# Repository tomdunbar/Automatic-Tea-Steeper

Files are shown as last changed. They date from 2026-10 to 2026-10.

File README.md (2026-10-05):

# Automatic Tea Steeper

A gravity-powered, electronics-free mechanical contraption that automatically steeps a tea bag for approximately five minutes, rings a bell once when steeping is complete, and lifts the tea bag out of the water.

The mechanism is essentially a clock built around a **flying pendulum escapement**, but without gears. The goal is functional mechanical art: a device that would look at home in a **Victorian inventor's parlor**.

> [!IMPORTANT]
> **Prototype / pre-fabrication design**
>
> The design has not yet been fabricated and validated as a complete assembly.
>
> The Bill of Materials (BOM) contains an **Updates** column documenting design changes made after the current CAD models and fabrication drawings were produced. Where an update is explicitly listed in the BOM, it represents the newer design intent. The CAD, STEP files, DWG files, and PDF drawings are being revised part-by-part to incorporate those changes.
>
> **Do not assume the current CAD and PDF drawings are fully synchronized with the BOM.**

## Overview

The device is powered by gravity. A suspended weight descends and pulls a string that drives both the main vertical shaft and the wheel/drum assembly.

A flying pendulum escapement slows the descent of the weight. A tea bag is attached to a peg on the wheel so that the wheel's rotation repeatedly raises and lowers the tea bag in a mug.

At the end of the steeping cycle:

1. The descending weight begins to load a small platform.
2. The platform causes the ball track to pivot.
3. A ball bearing or marble rolls down the track and strikes a bell once.
4. Rotation of the ball track also raises a bent lifting rod, which lifts the tea bag out of the mug.

The target steeping time is approximately **5 minutes**.

## Design Goals

- Fully mechanical operation — no electronics.
- Gravity-powered operation.
- Approximately five-minute steeping cycle.
- Repeated raising and lowering of the tea bag during steeping.
- Single audible bell strike when steeping is complete.
- Automatic removal of the tea bag from the water at the end of the cycle.
- Visually attractive brass / bronze / stainless-steel construction.
- An aesthetic inspired by Victorian scientific instruments and small model engines.
- A design that can be fabricated by a conventional machine shop using a mill and lathe, with CNC used where helpful.

## Main Mechanism

The main weight pulls a string as it descends. The string is wrapped around the main vertical shaft and around a drum on the horizontal wheel shaft.

As the string pays out:

- the main vertical shaft rotates;
- the wheel and drum rotate;
- the flying pendulum escapement controls the rate of rotation; and
- the tea bag moves up and down in the mug.

The flying pendulum uses offset upper and lower static arms. A small angular offset between the arms helps the pendulum string disengage cleanly and engage the upper arm first as it travels around the mechanism.

## Resetting the Device

To reset the steeper:

1. Place the flying pendulum bob onto the wire hook on the pendulum arm.
2. Turn the crank to rewind the drive string and raise the main weight.
3. Loop the pendulum bob over the upper static-arm support to prevent the mechanism from running.
4. Attach the tea-bag string to the peg on the wheel.
5. Position the mug.
6. Release the pendulum bob to start the steeping cycle.

## Steeping-Complete Mechanism

The notification mechanism is intended to strike a bell **one time** after approximately five minutes.

As the main weight reaches the bottom of its travel, it applies a small force to a platform. This pivots the ball track and releases a ball bearing or marble. The ball rolls down the track, strikes the bell, and is caught in a separate shallow dish.

A bent rod attached to the rear of the ball track acts as the **tea-bag lifter**. When the track pivots, the rod rotates upward and lifts the tea bag out of the mug.

## Major Subassemblies

- Main pillar and support
- Upper static arms
- Lower static arms
- Rotating / flying-pendulum assembly
- Wheel and drum
- Steeping-complete notification mechanism
- Tea-bag lifter
- Wooden base

## Design Parameters

Current design targets include:

| Parameter | Design goal / current value |
|---|---:|
| Steeping time | ~5 minutes |
| Main-weight travel | ~300 mm |
| Main shaft speed | >= 9 seconds/revolution |
| Main rotating rod diameter | 3 mm |

The steeping time is expected to depend on several variables, particularly the flying-pendulum string length. Other influences include pendulum mass, main-weight mass, static-arm spacing and angular offset, friction, and the amount of drive string released per revolution.

## Repository Status and Source Hierarchy

This repository is currently being organized and the design files are being reconciled.

| Source | Current role |
|---|---|
| **BOM — Updates column** | Latest design intent for the specific changes listed there |
| Native CAD / editable CAD | Intended to become the primary geometry source as parts are revised |
| STEP files | Neutral 3D exchange files; some currently predate BOM updates |
| DWG / fabrication drawing source | Drawing source; some currently predate BOM updates |
| PDF fabrication drawings | Published/printable drawing output; some currently predate BOM updates |
| Design Overview | Explanatory documentation; not a fabrication-control document |

The goal is for every fabrication part to have a synchronized set of:

1. editable/native CAD;
2. STEP export;
3. fabrication drawing source; and
4. PDF fabrication drawing.

## Planned Repository Organization

```text
Automatic-Tea-Steeper/
├── README.md
├── LICENSE
├── CHANGELOG.md
├── BOM/
│   └── BoM.xlsx
├── CAD/
│   ├── source/          # Editable/native CAD going forward
│   └── STEP/            # Neutral 3D exports
├── Drawings/
│   ├── source/          # Editable drawing files
│   └── PDF/             # Fabrication PDFs
├── Docs/
│   ├── Automatic_Tea_Steeper_Design_Overview.pptx
│   └── images/
└── Archive/
    └── original-cad-package/
```

The exact folder structure may evolve while the original CAD package is being reconciled.

## Design History / Roadmap

- [x] Concept and hand sketches
- [x] Initial CAD model and fabrication drawing package
- [x] Bill of Materials
- [x] Initial public GitHub repository
- [ ] Reconcile BOM design updates with CAD
- [ ] Establish editable native CAD source for revised parts
- [ ] Regenerate synchronized STEP files and fabrication PDFs
- [ ] Complete DFM / drawing review with machinist
- [ ] Fabricate first-round parts
- [ ] Test assembly and mechanism
- [ ] Revise design based on test results
- [ ] Fabricate second-round parts
- [ ] Complete and document final assembly

## Inspiration and References

The design was inspired in part by:

- **Chronova Engineering — bimetallic tea-monitoring mechanism**  
  https://www.youtube.com/watch?v=oJzy1vk2zyc

- **Kontax Stirling engines** — particularly the visible mechanical construction and brass/aluminum model-engine aesthetic  
  https://stirlingengine.co.uk/

- **Flying pendulum escapements**  
  Introduction: https://www.youtube.com/watch?v=z8V6RMJbHJc  
  Reference drawings: https://www.woodenclocks.co.uk/clock-17/

These references are provided for context and inspiration; third-party images, videos, trademarks, and designs remain the property of their respective owners.

## License

The original hardware design files in this repository are intended to be released under the **CERN Open Hardware Licence Version 2 – Permissive (CERN-OHL-P-2.0)**.

Commercial use is expressly welcome. You are free to build, modify, manufacture, and sell products based on this design, subject to the attribution and notice requirements of CERN-OHL-P-2.0.

See [`LICENSE`](LICENSE) for the complete license terms.

Third-party reference images, linked videos, trademarks, and other externally sourced material are **not** relicensed under the project license unless explicitly stated.

## Contributing

Fabrication, machining, DFM, CAD, and mechanism feedback is welcome. Issues and pull requests are especially useful for:

- identifying ambiguous or missing dimensions;
- improving machinability;
- correcting drawing/CAD inconsistencies;
- documenting fits and tolerances;
- reporting build results; and
- proposing improvements based on physical testing.

## Credits

Original mechanical concept and design: **Tom Dunbar**

Initial CAD and drawing package was produced from the original concept and hand drawings with outside CAD assistance.

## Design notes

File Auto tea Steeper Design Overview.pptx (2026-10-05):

## Automatic Tea Steeper Contraption Design Overview

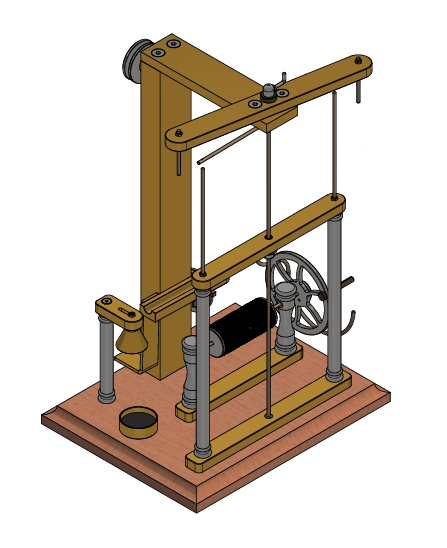
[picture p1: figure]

Design by Tom Dunbar

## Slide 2

This is a design for an automatic tea steeping contraption that is gravity powered and steeps a tea bag for approximately 5 minutes. After the steeping is complete, a bell is rung one time and the tea bag is lifted from the water. The contraption is based around a flying pendulum escapement so it contains no gears, despite it essentially being a clock.
The contraption was inspired by this delightfully over-engineered tea temperature monitoring mechanism: https://www.youtube.com/watch?v=oJzy1vk2zyc&list=PLxYRkul9JZoOfj6--7C8BmSLWSMhE7KK8&index=25&pp=gAQBiAQB
From this video, I liked the notification mechanism so much, I incorporated it into my design. I also like the aesthetic and functionality of the Kontax Stirling engine (https://stirlingengine.co.uk/products/KS90R-Ross-yoke-Aluminium-Stirling-Engine-p593670073), so I used some parts of it in the design. The goal is to create something that would look at home in a Victorian inventor’s parlor. As such, I did not want to use any electronics and wanted to use a ‘natural’ energy source e.g. gravity or the heat from the hot water.

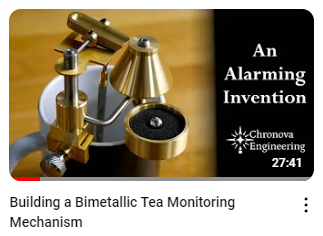
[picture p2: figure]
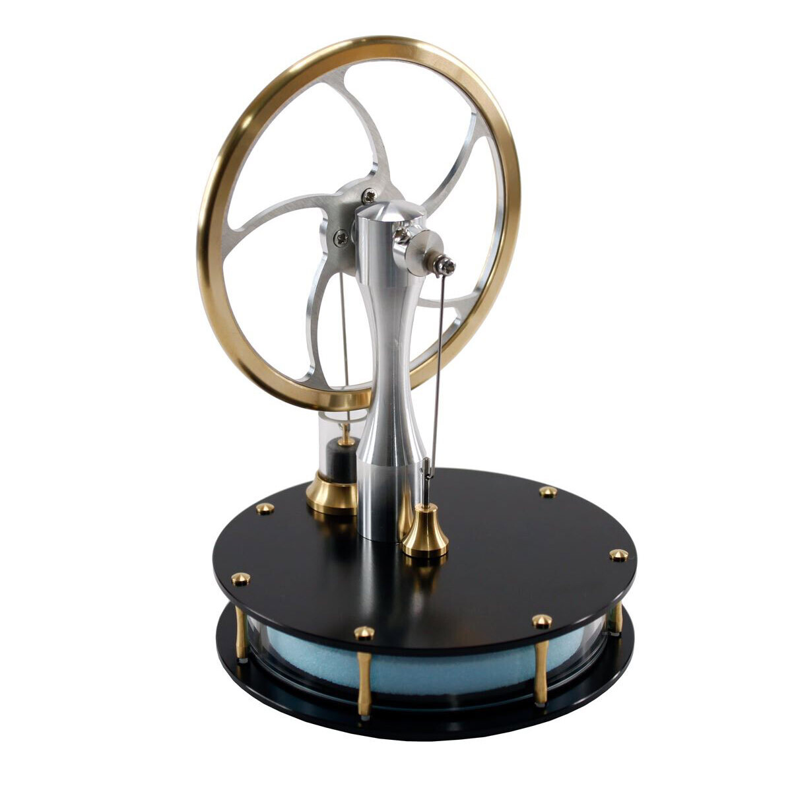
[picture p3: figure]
KS90 Aluminium Stirling Engine

## Main Mechanism Overview

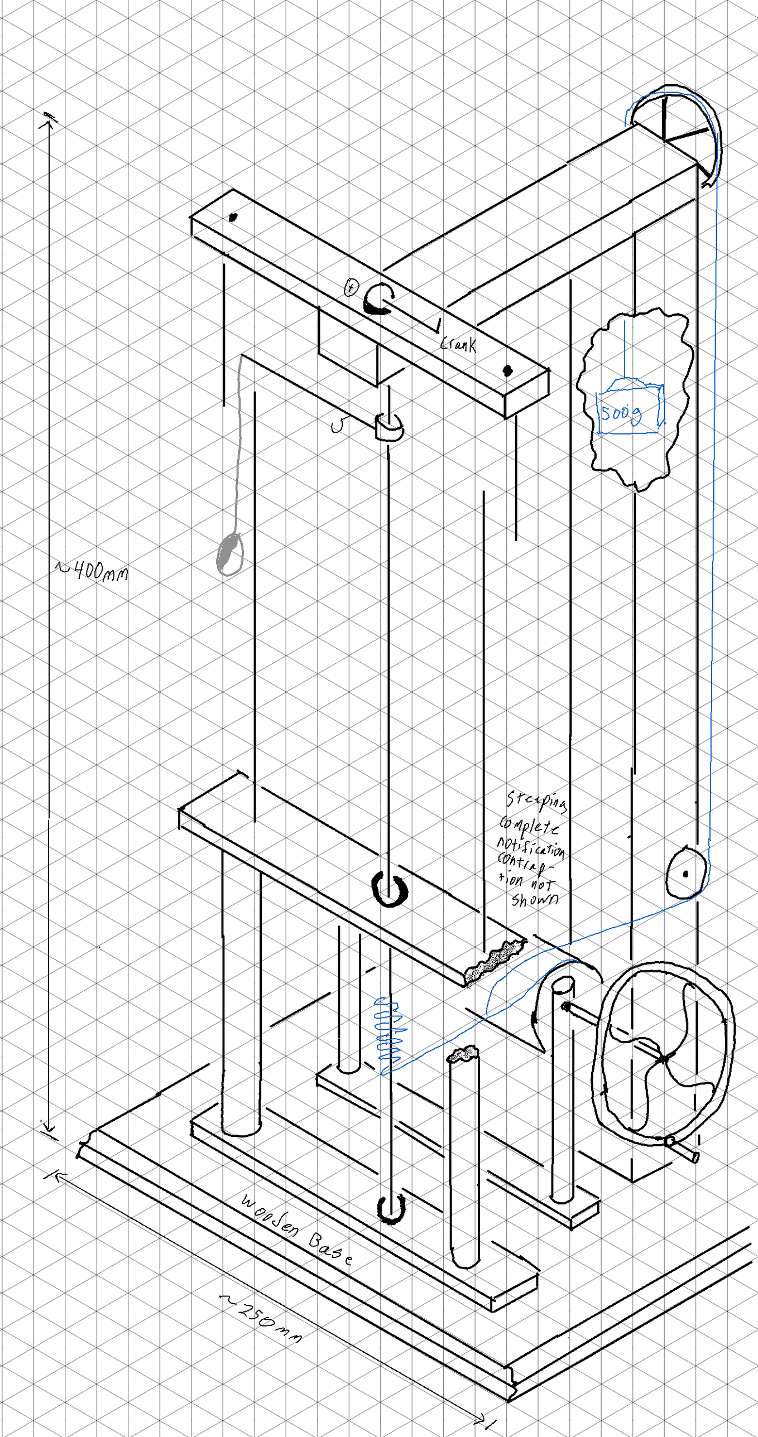
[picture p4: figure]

The mechanism works by gravity pulling the weight down, pulling on the string (blue).
The string is wrapped around a main vertical shaft and a drum. The drum is on a horizontal shaft with a wheel. As the string is played out, it causes the main vertical shaft to rotate as well as the drum/wheel to rotate.
The main shaft has a flying pendulum escapement to slow the weight’s decent.
A tea bag’s string is attached to a peg on the wheel and a mug of hot water is positioned below the wheel. As the wheel rotates, it slowly steeps the tea bag up and down.
As discussed later, after 5 minutes there is a steeping complete notification that rings a bell one time to alert the tea drinker that the tea is ready, similar to the notification in the inspiration video. The mechanism also lifts the tea bag out of the water.

## Flying Pendulum Escapement

- The link below is a good introduction to a flying pendulum and discusses some of the critical dimensions:
- https://www.youtube.com/watch?v=z8V6RMJbHJc
- The link below provides some good technical drawings of the escapement and some of the dimensions are visible in the PDF that you can view online. I used some of these dimensions when designing the device.
- https://www.woodenclocks.co.uk/clock-17/
- The following video is a bit long, but provided the original a-ha moment for how to actually accomplish the auto-steeping mechanism. The main mechanism is essentially a re-arrangement of his contraption:
- https://www.youtube.com/watch?v=uuelh5Yt9-Q

## Sub Assembles

- Main pillar and Support
- Upper static arms
- Lower static arms
- Rotating assembly
- Wheel & Drum
- Steeping complete notification contraption
- Wooden Base

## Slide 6

A slight offset (~10 degrees) between the upper and lower arms allows the string the disengage cleanly and helps it engage on the upper arm first when it swings around.
In this view, the pendulum is rotating counter-clockwise.

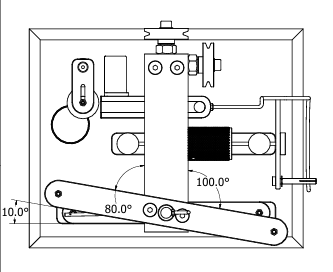
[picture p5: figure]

## Resetting the device

To reset the device, the flying pendulum bob is placed onto the wire hook that is on the pendulum arm. This allows the user to spin the crank without the pendulum bob wrapping around the static arms. This will wind up the string and prepare the weight for its next decent.
The pendulum bob is then looped over the upper static arm support beam to prevent the pendulum arm from moving (as seen in this video: https://www.youtube.com/watch?v=z8V6RMJbHJc)
When the pendulum is prevented from moving, the user can attach a tea bag’s string to the peg on the wheel and prepare a mug of hot water.
Un-looping the pendulum bob and letting go is all that is needed to start the main mechanism.

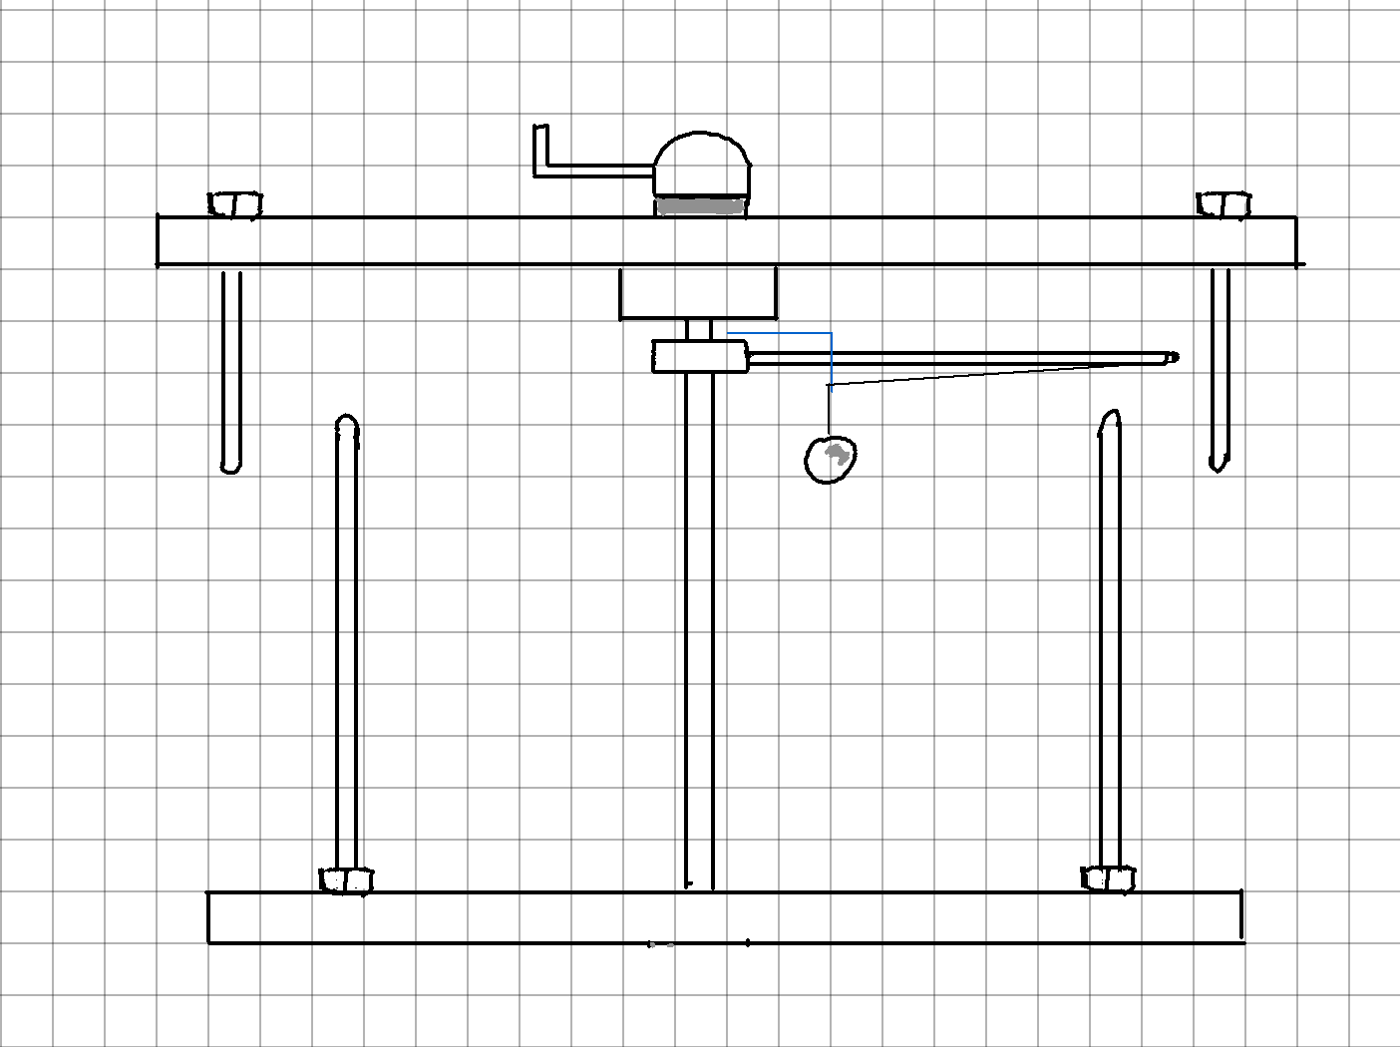
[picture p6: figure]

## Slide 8

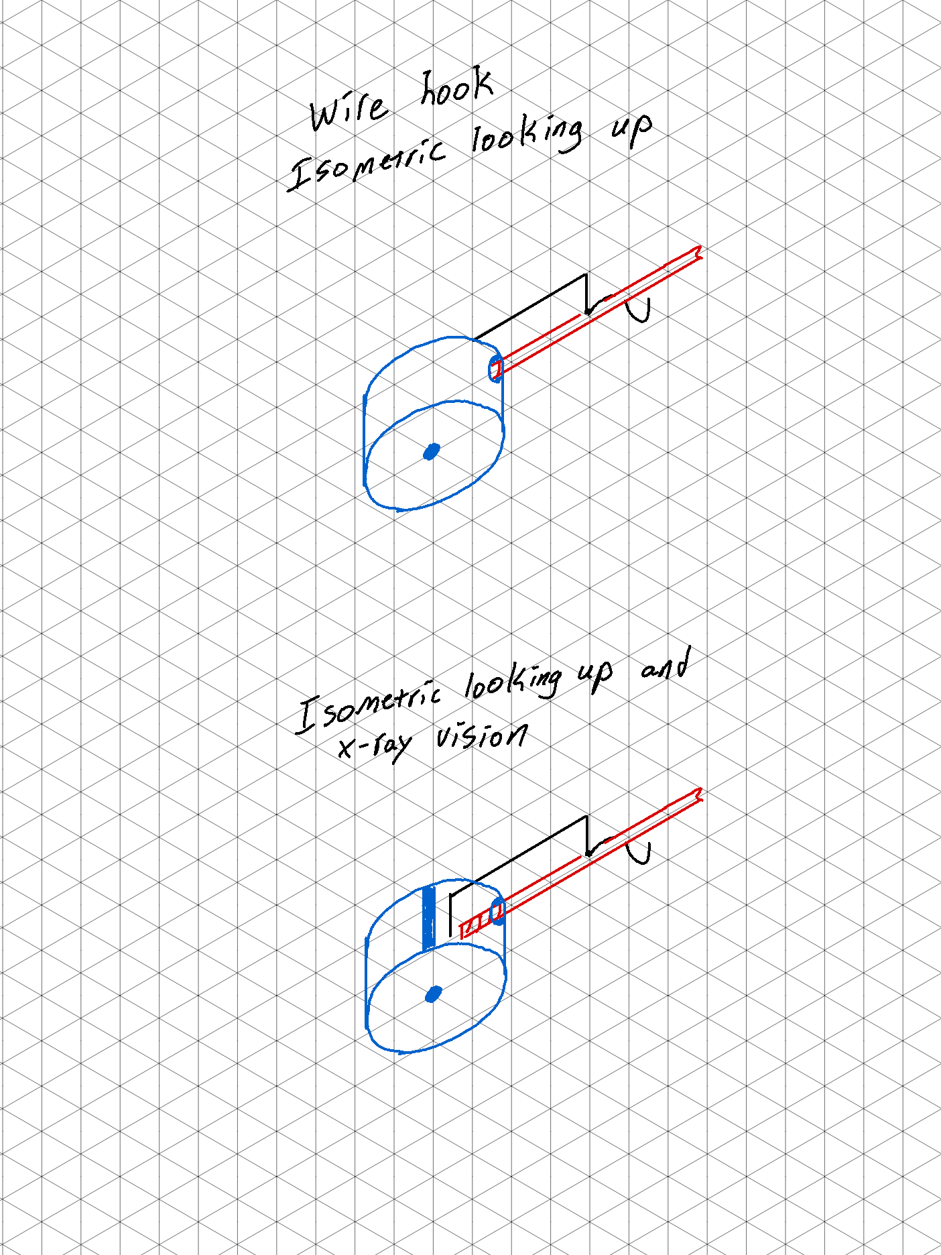
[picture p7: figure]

## Wheel and drum

Wheel is inspired by the Kontax Stirling Engine wheel

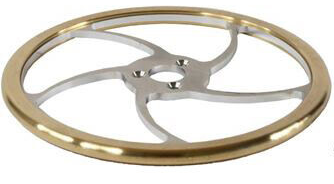
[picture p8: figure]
KS90 Flywheel
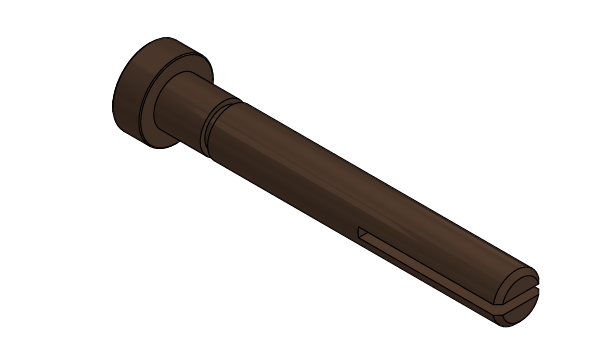
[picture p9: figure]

The tea bag’s string is held by the slot on the peg

## Steeping Complete Notification Contraption

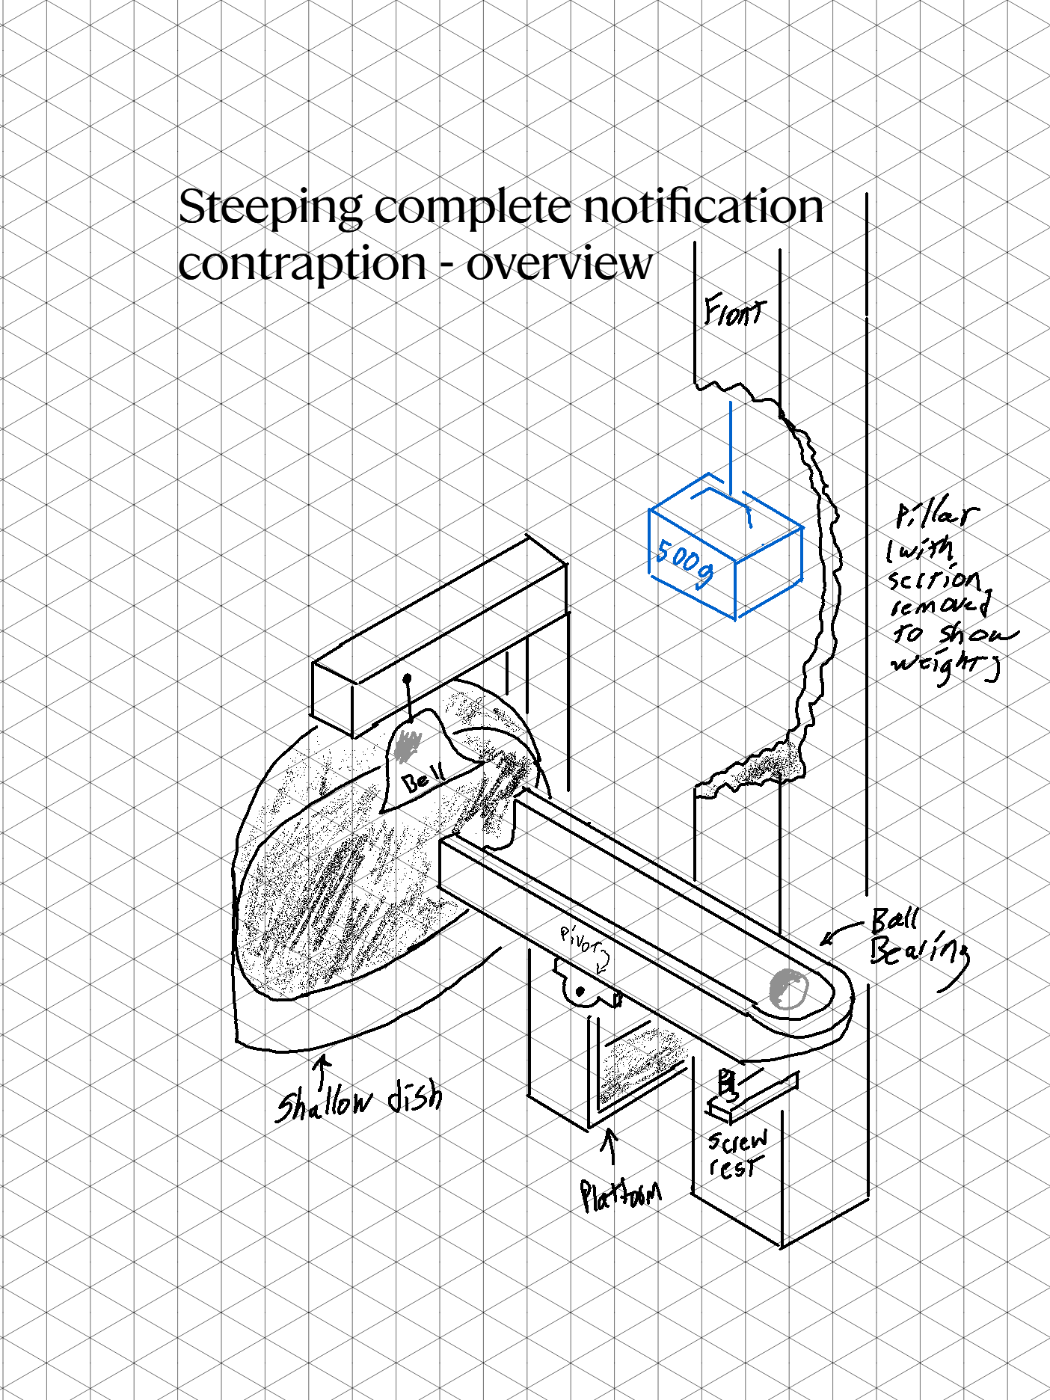
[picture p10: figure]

- This contraption is designed to strike a bell one time when steeping is complete, after approximately 5 minutes.
- The weight descends until it starts to rest on the platform. When the weight puts a small amount of force on the platform, a track pivots and a ball bearing (or marble) rolls down the track. The ball bearing strikes the bell and is caught in a shallow dish.
- The shallow dish is separate from the rest of the mechanism so it can be easily repositioned as necessary to catch the ball. It will likely include some padding to help catch the ball. If necessary, a small magnet can be placed under the padding to help retain the ball bearing.
- The inspiration for the bell notification mechanism came from video below. The whole video is worth watching, but skip to 19:30 if you just want to see the bell mechanism.
- https://www.youtube.com/watch?v=oJzy1vk2zyc&list=PLxYRkul9JZoOfj6--7C8BmSLWSMhE7KK8&index=25&pp=gAQBiAQB

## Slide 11

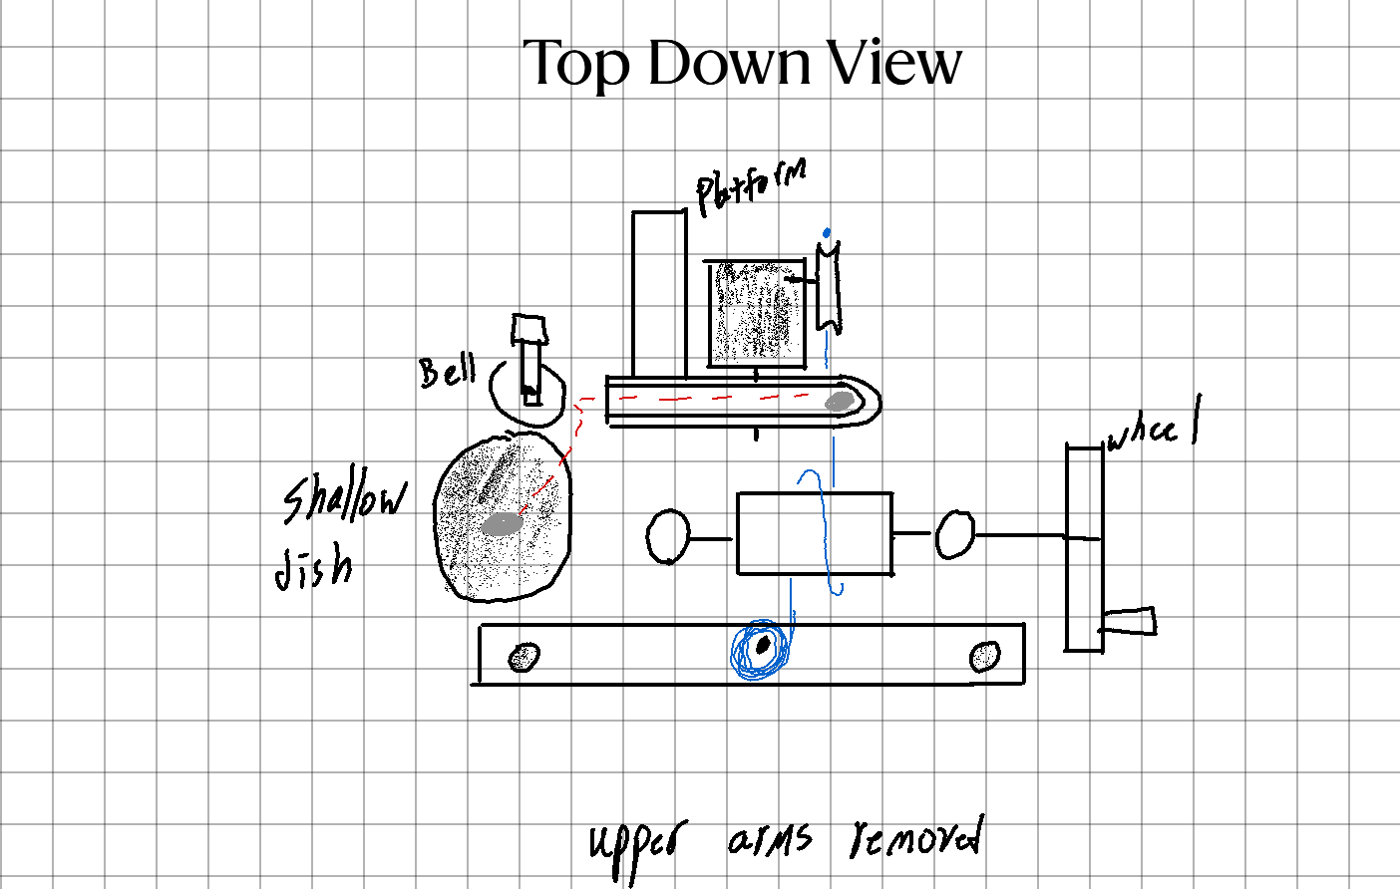
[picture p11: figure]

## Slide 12

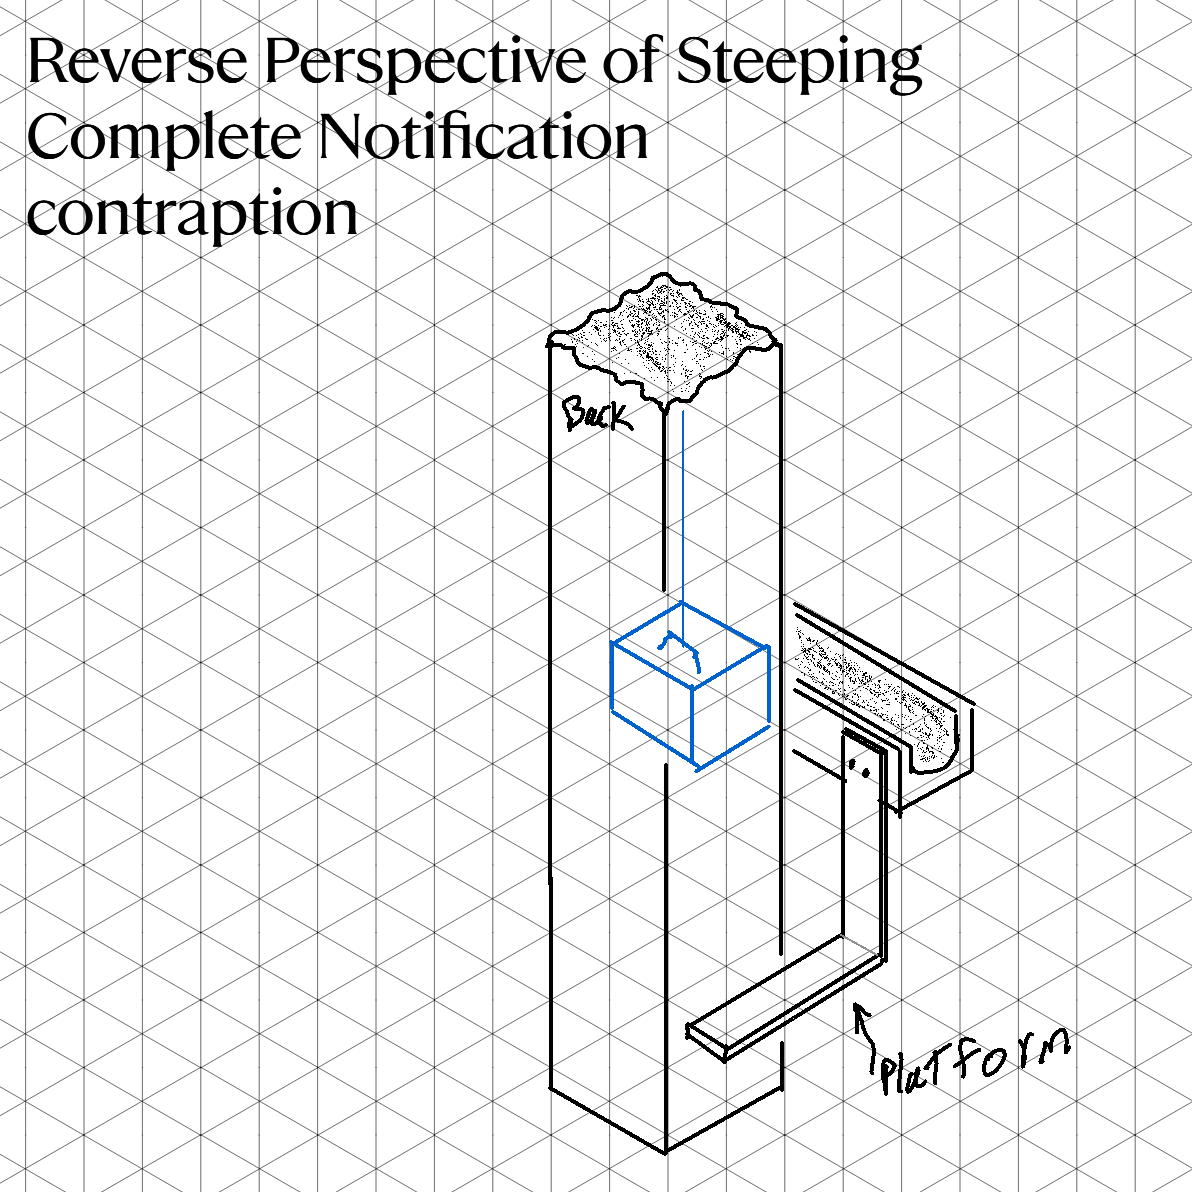
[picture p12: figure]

## Tea Bag Lifter Mechanism

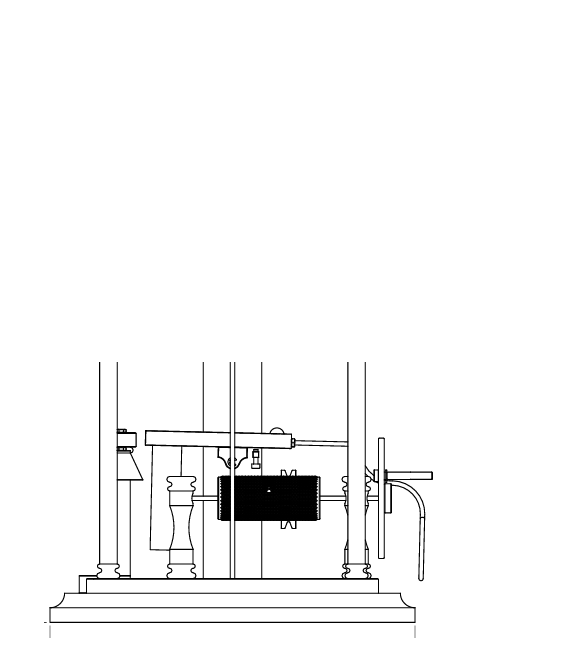
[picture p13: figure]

- Attached to the back of the ball track is a bent rod that is the tea bag lifter mechanism
- When the ball track rotates, the rod will rotate up, lifting the tea bag out of the mug

Tea Bag

Mug

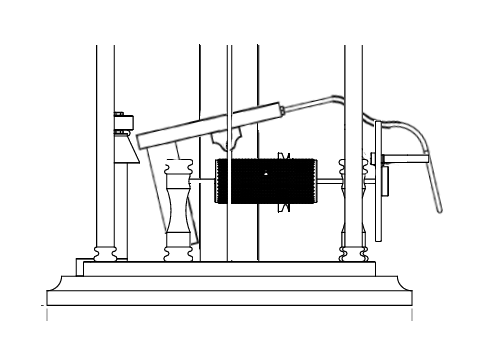
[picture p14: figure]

## Wooden Base

- Red Morrel Burl - https://www.youtube.com/watch?v=vFXsJNO3qsI
- Curly Koa is another good wood for a base
- But Walnut trophy bases are much less expensive:
  - https://www.jpplus.com/solid-walnut-plaque-base?sku=XP5114-EA
  - https://www.jpplus.com/roman-cove-edge-plaque?sku=W791-EA

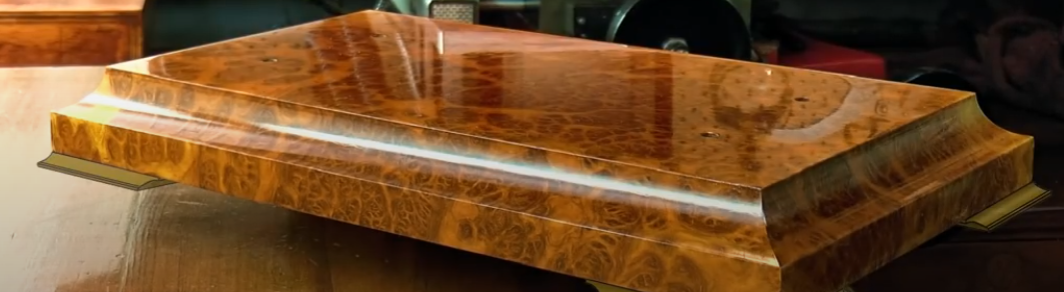
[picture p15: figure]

## Tea Organizer base

In order to have enough room for a mug underneath the wheel, I think the device might need to be placed on a stand like this tea organizer (https://www.etsy.com/listing/1542504095/custom-engraved-tea-organizer?ga_order=most_relevant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).
Alternatively , this type of chest/organizer could be built into the wooden base. It would be much more elegant this way, though difficult to find an artisan who can make a nice chest and do the machining.

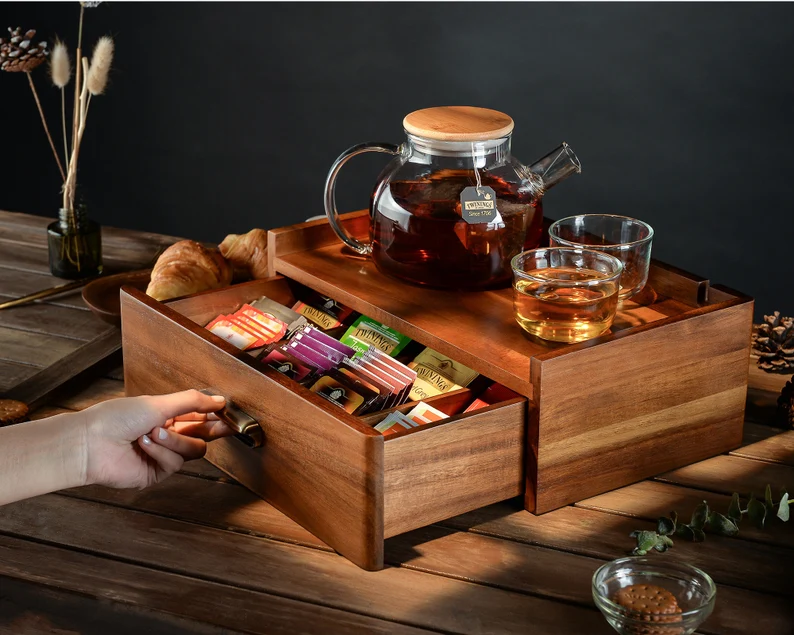
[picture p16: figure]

## String and Weight

- https://www.amazon.com/Slotted-Weight-Set-100g-Removable/dp/B08JM71KVX

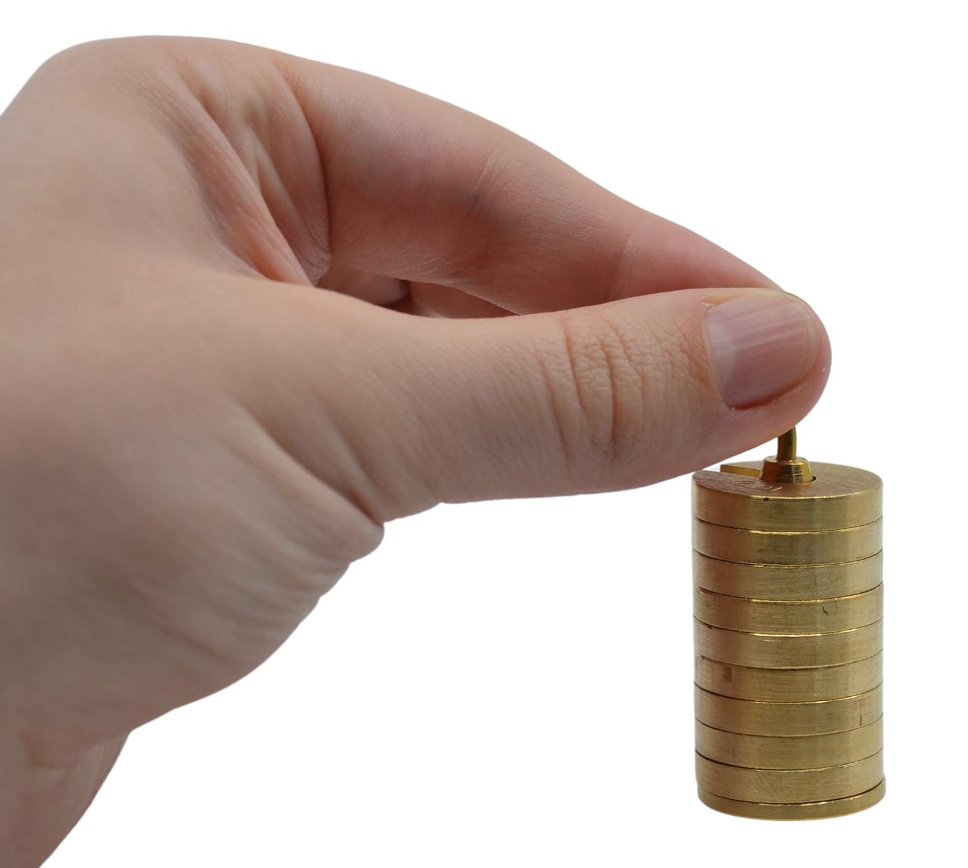
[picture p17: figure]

## Parameters influencing steeping time

- Length of main weight travel
  - Design goal: ~300 mm
- Seconds per rev (s/rev)
  - Design goal: ≥ 9 sec/rev
  - Pendulum string length has the largest influence on this parameter
  - Other factors include:
    - Pendulum weight
    - Mass of main weight
    - Distance between static arms (?)
    - Angle between upper and lower static arms
    - Friction
- String extended per rev (mm/rev)
  - Diameter of rotating rod (3mm)
  - Diameter * π

5min∗60(sec)/(min)= (seconds)/(rev) ∗(Length of Weight Travel(mm))/(string extended per rev ((mm)/(rev)))

300sec≈10 (sec)/(rev) ∗(300 mm)/(3π((mm)/(rev)))

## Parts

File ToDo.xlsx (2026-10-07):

# | Part / assembly | Recorded update | What needs reconciling | Material recommendation / decision
1 | 683ZZ Ball Bearing — Lower Static Arms item 4 | Changed to 683ZZ for commonality | Verify the .iam actually uses a 683ZZ; update parts list/drawing if it still says Ball Bearing-1. Confirm the bearing pocket in item 3 below matches it. | Purchased standard bearing; material choice is not important. 683ZZ is the useful specification.
2 | Allen Key 4×25 — Notification item 7 | “Changed M4 to 4” | Primarily nomenclature. Prefer M4 × 25 socket-head cap screw. Verify assembly component, BOM/iProperties, and drawing parts list. | Buy A2/304 stainless or ordinary plated steel. 440C is unnecessary for a general fastener.
3 | Lower Arm Brass Plate — Lower Static Arms item 1 | Bearing recess depth changed to 3 mm | Actual CAD geometry change. Update .ipt, then drawing and PDF. Your hand-redlined drawing already shows the pocket depth changed to 3.0 mm. | C36000 free-machining brass is my first choice.
4 | Domed End Rod 150 mm | Bronze → stainless | Material/iProperty change; geometry probably unchanged. Update assembly drawing/BOM automatically afterward. | 303 stainless is a good fit for a straight, machined 3 mm rod.
5 | Bush — Lower Static Arms item 6 | Bronze → stainless | ⚠ Contradiction: Preferred Material still says Bearing Bronze. Determine whether this is actually a bearing/bushing or merely a spacer. | If there is relative motion: C93200 / SAE 660 bearing bronze. I would not change a true bearing bush to stainless. If it is only a spacer, 303 SS is fine.
6 | CSK Allen Key 4×20 — Notification item 12 | Rename M4→4 and change to countersunk | Verify native assembly: Pack-and-Go already contains CSK Allen Key 4x20mm.ipt, so part of this update may already exist in CAD. Check the mating part for a countersink. | M4 × 20 hex-socket countersunk screw, preferably A2/304 stainless. ISO 10642 is the normal style. (ISO) (https://www.iso.org/standard/90795.html?utm_source=chatgpt.com)
7 | Ball Track Rest Pin | Bronze → stainless | ⚠ Contradiction: Preferred Material says Brass. Update material after deciding. | For a small contact/rest pin, I'd choose 303 stainless over brass: better wear resistance while still easy to machine.
8 | Tea Lifter Arm | Bronze → stainless | ⚠ Contradiction: Preferred Material says Aluminum. This is the bent rod shown in your mechanism description, so material affects bending. | 304 stainless, not 303. 303 is optimized for machining but has reduced formability and is a poor choice for sharp bends; 304 is much more appropriate here. (Atlas Steels) (https://atlassteels.com.au/documents/Atlas303.pdf?utm_source=chatgpt.com)
9 | Rotating Rod 370 mm | Bronze → stainless | Material/iProperty; verify any bearing/bushing fits but dimensions need not change merely for material. | 303 stainless, ideally straight/ground rod. If you want maximum availability rather than machinability, 304 is also fine.
10 | M4 Washer — Notification item 8 | Rename 4 mm → M4 | Nomenclature/BOM/iProperty only. | Standard A2 stainless washer. No need to specify a specialty alloy.
11 | M6 Washer — Main support item 22 | Rename 6 mm → M6; 1.6 mm thickness acceptable | Nomenclature and possibly native hardware component. | 1.6 mm is a normal-looking standard washer thickness. Use standard A2 stainless or plated steel; S355J2 isn't a useful washer specification.
12 | M8 Washer — Lower Static Arms item 9 | Rename 8 mm → M8 | Nomenclature only. | Standard A2 stainless or plated steel.
13 | M8 Washer — Main support item 23 | Rename 8 mm → M8 | Same as above. | Same.
14 | Pendulum Arm | Bronze → stainless | Material/iProperty. Check whether changing material affects timing enough to care during testing. | If it is machined: 303 stainless. If it involves substantial bending/forming: 304.
15 | Brass Plate — Upper Static Arms item 1 | Outer holes M2 → M3; only bottom half tapped | Actual CAD geometry/thread change. Current drawing still specifies 2×M2 Thread. We need to define exactly what “bottom half tapped” means before editing. | C360 brass. Geometry decision still required: for a 10 mm plate, do you mean ~5 mm of M3 thread with an M3 clearance bore above it? We should resolve this before opening Inventor.
16 | Bush — Upper Static Arms item 2 | Bronze → stainless | ⚠ Contradiction: Preferred Material still says Bearing Bronze. Same functional question as item 5. | Again, if this is a real sliding/rotating bush, C932 bearing bronze is the better engineering choice.
17 | Domed End Rod 40 mm | Bronze → stainless | Material/iProperty. | 303 stainless for the short machined rod.
18 | Wheel Shaft 125 mm | Bronze → stainless | Material/iProperty; verify bearing/journal fits. | 303 stainless is appropriate at these light loads. Precision-ground stock would be ideal where it passes through bearings.

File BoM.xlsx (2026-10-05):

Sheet: BoM
SubAssembly | Subassembly item Number | PART NAME | LENGTH | WIDTH | THICKNESS | PREFFERED MATERIAL | DIAMETER | QTY | Procurement | Updates
Main Piller And Support | 12 | 3mm E Clip |  |  |  | Steel |  | 2 | Buy
Steeping Complete Notification | 11 | 3mm Rubber Washer |  |  | 0.500 mm | Rubber | 7.000 mm | 1 | Buy
Wheel And Drum | 15 | 4mm E Clip |  |  |  | Stainless Steel |  | 1 | Buy
Main Piller And Support | 11 | 61800 Bearing |  |  |  | Stainless Steel, Austenitic |  | 2 | Buy
Lower Static Arms | 4 | 683ZZ Ball Bearing |  |  |  | Steel, Alloy |  | 1 | Buy | Changed to 683ZZ for commonality
Wheel And Drum | 9 | 683ZZ Ball Bearing |  |  |  | Steel, Alloy |  | 3 | Buy
Main Piller And Support | 24 | Allen Key 3x10mm |  |  |  | Stainless Steel, 440C |  | 1 | Buy
Steeping Complete Notification | 10 | Allen Key 3x16mm |  |  |  | Stainless Steel, 440C |  | 1 | Buy
Main Piller And Support | 16 | Allen Key 3x5mm |  |  |  | Stainless Steel, 440C |  | 1 | Buy
Steeping Complete Notification | 7 | Allen Key 4x25 |  |  |  | Stainless Steel, 440C |  | 1 | Buy | Changed M4 to 4
Main Piller And Support | 17 | Allen Key 6x12mm |  |  |  | Stainless Steel, 440C |  | 2 | Buy
Main Piller And Support | 18 | Allen Key 8x25mm |  |  |  | Steel, Mild |  | 2 | Buy
Lower Static Arms | 7 | Allen Key 8x40mm |  |  |  | Steel, Mild |  | 2 | Buy
Wheel And Drum | 10 | Allen Key 8x40mm |  |  |  | Steel, Mild |  | 2 | Buy
Main Piller And Support | 10 | Ball |  |  |  | Stainless Steel | 10.000 mm | 1 | Buy
Lower Static Arms | 1 | Lower Arm Brass Plate | 10.000 mm | 20.000 mm | 200.000 mm | Brass, Soft Yellow |  | 1 | Fabricate 1st Round | Changed depth to 3mm for 683ZZ bearing
Lower Static Arms | 2 | Lower Arm Support |  |  | 190.000 mm | Stainless Steel | 16.000 mm | 2 | Fabricate 1st Round
Lower Static Arms | 3 | Lower Arm Brass Plate - 2 | 10.000 mm | 20.000 mm | 190.000 mm | Brass, Soft Yellow |  | 1 | Fabricate 1st Round
Lower Static Arms | 5 | Domed End Rod 150mm |  |  | 140.000 mm | Stainless Steel | 3.000 mm | 2 | Fabricate 1st Round | Changed material from Bronze to Stainless Steel
Lower Static Arms | 6 | Bush |  |  | 15.000 mm | Bearing Bronze | 15.000 mm | 1 | Fabricate 1st Round | Changed material from Bronze to Stainless Steel
Main Piller And Support | 1 | Main Piller | 345.000 mm | 40.000 mm | 25.000 mm | Brass, Soft Yellow |  | 1 | Fabricate 1st Round
Main Piller And Support | 2 | Support Beam | 162.500 mm | 40.000 mm | 10.000 mm | Brass, Soft Yellow |  | 1 | Fabricate 1st Round
Lower Static Arms | 8 | Brass M3 Hex Nut |  |  |  | Brass, Soft Yellow |  | 2 | Buy
Main Piller And Support | 14 | Brass M3 Hex Nut |  |  |  | Brass, Soft Yellow |  | 2 | Buy
Upper Static Arms | 4 | Brass M3 Hex Nut |  |  |  | Brass, Soft Yellow |  | 2 | Buy
Main Piller And Support | 3 | Ball Track | 100.000 mm | 20.000 mm | 10.000 mm | Brass, Soft Yellow |  | 1 | Fabricate 2nd Round
Main Piller And Support | 4 | Ball Track Mounting Plate | 20.000 mm | 20.000 mm | 10.000 mm | Brass, Soft Yellow |  | 1 | Fabricate 2nd Round
Main Piller And Support | 5 | Ball Track Support | 42.000 mm |  |  | Bronze, Soft Tin | 3.000 mm | 1 | Fabricate 2nd Round
Main Piller And Support | 19 | CSK Allen Key 3x8mm |  |  |  | Steel, Mild |  | 2 | Buy
Wheel And Drum | 11 | CSK Allen Key 3x8mm |  |  |  | Steel, Mild |  | 2 | Buy
Steeping Complete Notification | 12 | CSK Allen Key 4x20 |  |  |  | Steel, Mild |  | 1 | Buy | Changed M4 to 4, updated to CSK
Upper Static Arms | 5 | CSK Allen Key 6x20mm |  |  |  | Steel, Mild |  | 2 | Buy
Main Piller And Support | 20 | CSK Allen Key 6x25mm |  |  |  | Steel, Mild |  | 2 | Buy
Main Piller And Support | 6 | Ball Track Rest Pin | 42.000 mm |  |  | Brass, Soft Yellow |  | 1 | Fabricate 2nd Round | Changed material from Bronze to Stainless Steel
Main Piller And Support | 7 | Pully | 10.000 mm |  |  | Steel, Cast | 40.000 mm | 2 | Fabricate 1st Round
Main Piller And Support | 8 | Pully Shaft | 37.550 mm |  |  | Steel, Alloy | 15.000 mm | 2 | Fabricate 1st Round
Steeping Complete Notification | 6 | Foam Pad |  |  |  | Polystyrene |  | 1 | Buy
Main Piller And Support | 21 | Grub Screw 3x3mm |  |  |  | Stainless Steel, 440C |  | 1 | Buy
Rotating Assembly | 8 | Grub Screw 3x3mm |  |  |  | Stainless Steel, 440C |  | 1 | Buy
Wheel And Drum | 12 | Grub Screw 3x8mm |  |  |  | Stainless Steel, 440C |  | 1 | Buy
Wheel And Drum | 13 | Grub Screw 5x12mm |  |  |  | Stainless Steel, 440C |  | 1 | Buy
Main Piller And Support | 13 | Internal 19mm Circlips |  |  |  | Stainless Steel 316L |  | 2 | Buy
Main Piller And Support | 9 | Platform | 218.000 mm | 20.000 mm | 3.000 mm | Brass, Soft Yellow |  | 1 | Fabricate 2nd Round
Main Piller And Support | 26 | Tea Lifter Arm |  |  |  | Aluminum | 3.000 mm | 1 | Fabricate 2nd Round | Changed material from Bronze to Stainless Steel
Rotating Assembly | 1 | Rotating Rod 370mm | 370.000 mm |  |  | Stainless Steel | 3.000 mm | 1 | Fabricate 1st Round | Changed material from Bronze to Stainless Steel
Rotating Assembly | 2 | Top Lock Cap | 10.000 mm |  |  | Mild Steel S355 J2 | 10.000 mm | 1 | Fabricate 1st Round
Rotating Assembly | 3 | Lock Handel | 35.000 mm |  |  | Mild Steel S355 J2 | 3.000 mm | 1 | Fabricate 1st Round
Rotating Assembly | 4 | Pendulum Arm Cap | 6.000 mm |  |  | Stainless Steel | 10.000 mm | 1 | Fabricate 1st Round
Main Piller And Support | 15 | M10 Hex Nut |  |  |  | Stainless Steel, 440C |  | 2 | Buy
Rotating Assembly | 7 | M3 Hex Nut |  |  |  | Stainless Steel, 440C |  | 2 | Buy
Steeping Complete Notification | 9 | M3 Hex Nut |  |  |  | Stainless Steel, 440C |  | 2 | Buy
Steeping Complete Notification | 8 | M4 Washer |  |  |  | Stainless Steel |  | 1 | Buy | Changed 4mm to M4,
Main Piller And Support | 22 | M6 Washer |  |  | 2.000 mm | Mild Steel S355 J2 | 12.000 mm | 2 | Buy | Changed 6mm to M6, fine to have 1.6mm thickness
Lower Static Arms | 9 | M8 Washer |  |  |  | Stainless Steel |  | 2 | Buy | Changed 8mm to M8
Main Piller And Support | 23 | M8 Washer |  |  |  | Stainless Steel |  | 2 | Buy | Changed 8mm to M8
Wheel And Drum | 14 | M8 Washer |  |  |  | Stainless Steel |  | 2 | Buy
Steeping Complete Notification | 5 | Magnet |  |  |  | Magnesium AZ63A |  | 1 | Buy
Rotating Assembly | 5 | Pendulum Arm | 92.000 mm |  |  | Stainless Steel |  | 1 | Fabricate 1st Round | Changed material from Bronze to Stainless Steel
Rotating Assembly | 6 | Lower Lock Cap | 7.000 mm |  |  | Mild Steel S355 J2 | 10.000 mm | 1 | Fabricate 1st Round
Steeping Complete Notification | 1 | Bell Support Piller | 100.000 mm |  |  | Stainless Steel | 16.000 mm | 1 | Fabricate 2nd Round
Rotating Assembly | 100 | Pendulum Bob |  |  |  | Lead |  | 1 | Buy
Steeping Complete Notification | 2 | Bell Support Beam | 50.000 mm | 20.000 mm | 10.000 mm | Brass, Soft Yellow |  | 1 | Fabricate 2nd Round
Steeping Complete Notification | 3 | Bell | 20.000 mm |  |  | Brass, Soft Yellow | 30.000 mm | 1 | Fabricate 2nd Round
Steeping Complete Notification | 4 | Shallow Dish | 12.000 mm |  |  | Brass, Soft Yellow | 35.000 mm | 1 | Fabricate 2nd Round
Upper Static Arms | 1 | Brass Plate | 225.000 mm | 25.000 mm | 10.000 mm | Brass, Soft Yellow |  | 1 | Fabricate 1st Round | outter most holes should be tapped M3, and only the bottom half of the hole shold be tapped
Upper Static Arms | 2 | Bush | 15.000 mm |  |  | Bearing bronze | 15.000 mm | 1 | Fabricate 1st Round | Changed material from Bronze to Stainless Steel
Main Piller And Support | 100 | String |  |  |  | Nylon |  | 1 | Buy
Rotating Assembly | 101 | String |  |  |  | Nylon |  | 1 | Buy
Upper Static Arms | 3 | Domed End Rod 40mm | 50.000 mm |  |  | Stainless Steel | 3.000 mm | 2 | Fabricate 1st Round | Changed material from Bronze to Stainless Steel
Wheel And Drum | 1 | Lower Arm Brass Plate - 3 | 150.000 mm | 20.000 mm | 10.000 mm | Brass, Soft Yellow |  | 1 | Fabricate 2nd Round
Wheel And Drum | 2 | Wheel Shaft 125mm | 139.500 mm |  |  | Stainless steel | 3.000 mm | 1 | Fabricate 2nd Round | Changed material from Bronze to Stainless Steel
Main Piller And Support | 101 | Weight |  |  |  | Lead |  | 1 | Buy
Wheel And Drum | 3 | Wheel |  |  | 4.000 mm | Mild Steel S355 J2 | 82.500 mm | 1 | Fabricate 2nd Round
Wheel And Drum | 4 | Wheel Mounting Cap |  |  | 5.000 mm | Mild Steel S355 J2 | 20.000 mm | 1 | Fabricate 2nd Round
Wheel And Drum | 5 | Drum | 70.000 mm |  |  | Steel, Mild | 30.000 mm | 1 | Fabricate 2nd Round
Wheel And Drum | 6 | Wheel Handle | 37.000 mm |  |  | Bronze, Soft Tin | 5.000 mm | 1 | Fabricate 2nd Round
Wheel And Drum | 7 | Wheel Shaft Pillar | 70.000 mm |  |  | Stainless Steel | 20.000 mm | 1 | Fabricate 2nd Round
Wheel And Drum | 8 | Wheel Shaft Pillar - 2 | 70.000 mm |  |  | Stainless Steel | 20.000 mm | 1 | Fabricate 2nd Round
Rotating Assembly | 102 | Wire |  |  |  | Steel |  | 1 | Buy
Wooden Base | 1 | Wooden Base | 200 mm | 250 mm | 20mm | Wood, Walnut |  | 1 | Fabricate 1st Round

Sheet: SubAssemblies
Wooden Base
Main Piller And Support
Upper Static Arms
Lower Static Arms
Wheel And Drum
Rotating Assembly
Steeping Complete Notification

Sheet: BoM - Backup
SubAssembly | Subassembly item Number | PART NAME | LENGTH | WIDTH | THICKNESS | MATERIAL | DIAMETER | QTY | SQUARE BAR
Main Piller And Support | 1 | Main Piller | 345.000 mm | 40.000 mm | 25.000 mm | Brass, Soft Yellow |  | 1
Main Piller And Support | 2 | Support Beam | 162.500 mm | 40.000 mm | 10.000 mm | Brass, Soft Yellow |  | 1
Main Piller And Support | 3 | Ball Track | 100.000 mm | 20.000 mm | 10.000 mm | Brass, Soft Yellow |  | 1
Main Piller And Support | 4 | Ball Track Mounting Plate | 20.000 mm | 20.000 mm | 10.000 mm | Brass, Soft Yellow |  | 1
Main Piller And Support | 5 | Ball Track Support | 42.000 mm |  |  | Bronze, Soft Tin | 3.000 mm | 1
Main Piller And Support | 6 | Ball Track Rest Pin | 42.000 mm |  |  | Bronze, Soft Tin |  | 1 | 4 mm x 4 mm
Main Piller And Support | 7 | Pully | 10.000 mm |  |  | Steel, Cast | 40.000 mm | 2
Main Piller And Support | 8 | Pully Shaft | 37.550 mm |  |  | Steel, Alloy | 15.000 mm | 2
Main Piller And Support | 9 | Platform | 218.000 mm | 20.000 mm | 3.000 mm | Brass, Soft Yellow |  | 1
Main Piller And Support | 10 | Ball |  |  |  | Stainless Steel | 10.000 mm | 1
Main Piller And Support | 11 | 61800 Bearing |  |  |  | Stainless Steel, Austenitic |  | 2
Main Piller And Support | 12 | 3mm E Clip |  |  |  | Steel |  | 2
Main Piller And Support | 13 | Internal 19mm Circlips |  |  |  | Stainless Steel 316L |  | 2
Main Piller And Support | 14 | Brass M3 Hex Nut |  |  |  | Brass, Soft Yellow |  | 2
Main Piller And Support | 15 | M10 Hex Nut |  |  |  | Stainless Steel, 440C |  | 2
Main Piller And Support | 16 | Allen Key 3x5mm |  |  |  | Stainless Steel, 440C |  | 1
Main Piller And Support | 17 | Allen Key 6x12mm |  |  |  | Stainless Steel, 440C |  | 2
Main Piller And Support | 18 | Allen Key 8x25mm |  |  |  | Steel, Mild |  | 2
Main Piller And Support | 19 | CSK Allen Key 3x8mm |  |  |  | Steel, Mild |  | 2
Main Piller And Support | 20 | CSK Allen Key 6x25mm |  |  |  | Steel, Mild |  | 2
Main Piller And Support | 21 | Grub Screw 3x3mm |  |  |  | Stainless Steel, 440C |  | 1
Main Piller And Support | 22 | 6mm Washer |  |  | 2.000 mm | Mild Steel S355 J2 | 12.000 mm | 2
Main Piller And Support | 23 | 8mm Washer |  |  |  | Stainless Steel |  | 2
Main Piller And Support | 24 | Allen Key 3x10mm |  |  |  | Stainless Steel, 440C |  | 1
Main Piller And Support | 26 | Tea Lifter Arm |  |  |  | Bronze, Soft Tin | 3.000 mm | 1
Lower Static Arms | 1 | Lower Arm Brass Plate | 10.000 mm | 20.000 mm | 200.000 mm | Brass, Soft Yellow |  | 1
Lower Static Arms | 2 | Lower Arm Support |  |  | 190.000 mm | Stainless Steel | 16.000 mm | 2
Lower Static Arms | 3 | Lower Arm Brass Plate - 2 | 10.000 mm | 20.000 mm | 190.000 mm | Brass, Soft Yellow |  | 1
Lower Static Arms | 4 | Ball Bearing-1 |  |  |  | Steel, Alloy |  | 1
Lower Static Arms | 5 | Domed End Rod 150mm |  |  | 140.000 mm | Bronze, Soft Tin | 3.000 mm | 2
Lower Static Arms | 6 | Bush |  |  | 15.000 mm | Bronze, Soft Tin | 15.000 mm | 1
Lower Static Arms | 7 | Allen Key 8x40mm |  |  |  | Steel, Mild |  | 2
Lower Static Arms | 8 | Brass M3 Hex Nut |  |  |  | Brass, Soft Yellow |  | 2
Lower Static Arms | 9 | 8mm Washer |  |  |  | Stainless Steel |  | 2
Upper Static Arms | 1 | Brass Plate | 225.000 mm | 25.000 mm | 10.000 mm | Brass, Soft Yellow |  | 1
Upper Static Arms | 2 | Bush | 15.000 mm |  |  | Bronze, Soft Tin | 15.000 mm | 1
Upper Static Arms | 3 | Domed End Rod 40mm | 50.000 mm |  |  | Bronze, Soft Tin | 3.000 mm | 2
Upper Static Arms | 4 | Brass M3 Hex Nut |  |  |  | Brass, Soft Yellow |  | 2
Upper Static Arms | 5 | CSK Allen Key 6x20mm |  |  |  | Steel, Mild |  | 2
Wooden Base | 1 | Wooden Base | 200 mm | 250 mm | 20mm | Wood, Walnut |  | 1
Wheel And Drum | 1 | Lower Arm Brass Plate - 3 | 150.000 mm | 20.000 mm | 10.000 mm | Brass, Soft Yellow |  | 1
Wheel And Drum | 2 | Wheel Shaft 125mm | 139.500 mm |  |  | Bronze, Soft Tin | 3.000 mm | 1
Wheel And Drum | 3 | Wheel |  |  | 4.000 mm | Mild Steel S355 J2 | 82.500 mm | 1
Wheel And Drum | 4 | Wheel Mounting Cap |  |  | 5.000 mm | Mild Steel S355 J2 | 20.000 mm | 1
Wheel And Drum | 5 | Drum | 70.000 mm |  |  | Steel, Mild | 30.000 mm | 1
Wheel And Drum | 6 | Wheel Handle | 37.000 mm |  |  | Bronze, Soft Tin | 5.000 mm | 1
Wheel And Drum | 7 | Wheel Shaft Pillar | 70.000 mm |  |  | Stainless Steel | 20.000 mm | 1
Wheel And Drum | 8 | Wheel Shaft Pillar - 2 | 70.000 mm |  |  | Stainless Steel | 20.000 mm | 1
Wheel And Drum | 9 | 683ZZ Ball Bearing |  |  |  | Steel, Alloy |  | 3
Wheel And Drum | 10 | Allen Key 8x40mm |  |  |  | Steel, Mild |  | 2
Wheel And Drum | 11 | CSK Allen Key 3x8mm |  |  |  | Steel, Mild |  | 2
Wheel And Drum | 12 | Grub Screw 3x8mm |  |  |  | Stainless Steel, 440C |  | 1
Wheel And Drum | 13 | Grub Screw 5x12mm |  |  |  | Stainless Steel, 440C |  | 1
Wheel And Drum | 14 | M8 Washer |  |  |  | Stainless Steel |  | 2
Wheel And Drum | 15 | 4mm E Clip |  |  |  | Stainless Steel |  | 1
Rotating Assembly | 1 | Rotating Rod 370mm | 370.000 mm |  |  | Bronze, Soft Tin | 3.000 mm | 1
Rotating Assembly | 2 | Top Lock Cap | 10.000 mm |  |  | Mild Steel S355 J2 | 10.000 mm | 1
Rotating Assembly | 3 | Lock Handel | 35.000 mm |  |  | Mild Steel S355 J2 | 3.000 mm | 1
Rotating Assembly | 4 | Pendulum Arm Cap | 6.000 mm |  |  | Stainless Steel | 10.000 mm | 1
Rotating Assembly | 5 | Pendulum Arm | 92.000 mm |  |  | Bronze, Soft Tin |  | 1
Rotating Assembly | 6 | Lower Lock Cap | 7.000 mm |  |  | Mild Steel S355 J2 | 10.000 mm | 1
Rotating Assembly | 7 | M3 Hex Nut |  |  |  | Stainless Steel, 440C |  | 2
Rotating Assembly | 8 | Grub Screw 3x3mm |  |  |  | Stainless Steel, 440C |  | 1
Steeping Complete Notification | 1 | Bell Support Piller | 100.000 mm |  |  | Stainless Steel | 16.000 mm | 1
Steeping Complete Notification | 2 | Bell Support Beam | 50.000 mm | 20.000 mm | 10.000 mm | Brass, Soft Yellow |  | 1
Steeping Complete Notification | 3 | Bell | 20.000 mm |  |  | Brass, Soft Yellow | 30.000 mm | 1
Steeping Complete Notification | 4 | Shallow Dish | 12.000 mm |  |  | Brass, Soft Yellow | 35.000 mm | 1
Steeping Complete Notification | 5 | Magnet |  |  |  | Magnesium AZ63A |  | 1
Steeping Complete Notification | 6 | Foam Pad |  |  |  | Polystyrene |  | 1
Steeping Complete Notification | 7 | Allen Key M4 x 25 |  |  |  | Stainless Steel, 440C |  | 1
Steeping Complete Notification | 8 | 4mm Washer |  |  |  | Stainless Steel |  | 1
Steeping Complete Notification | 9 | M3 Hex Nut |  |  |  | Stainless Steel, 440C |  | 2
Steeping Complete Notification | 10 | Allen Key 3x16mm |  |  |  | Stainless Steel, 440C |  | 1
Steeping Complete Notification | 11 | 3mm Rubber Washer |  |  | 0.500 mm | Rubber | 7.000 mm | 1
Steeping Complete Notification | 12 | Allen Key - M4x20 |  |  |  | Steel, Mild |  | 1

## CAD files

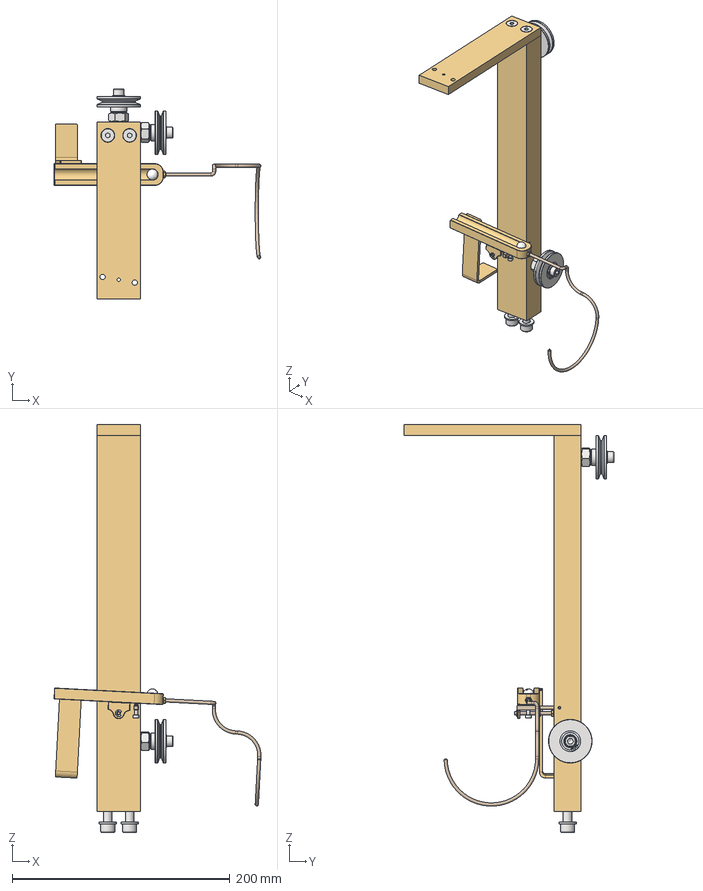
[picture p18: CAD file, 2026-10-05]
CAD/Workspace/Main Piller And Support.stp
190.0 x 192.5 x 374.5 mm
Main Piller
Support Beam
CSK Allen Key 6x25mm x 2
Allen Key 8x25mm x 2
Pully Shaft x 2
M10 Hex Nut x 2
Pully x 2
Internal 19mm Circlips x 2
61800 Bearing x 2
6mm Washer x 2
Allen Key 6x12mm x 2
Ball Track
Ball Track Mounting Plate
Ball Track Support
Brass M3 Hex Nut x 2
3mm E Clip x 2
Platform
CSK Allen Key 3x8mm x 2
Allen Key 3x5mm
Ball
Ball Track Rest Pin
Grub Screw 3x3mm
8mm Washer x 2
Allen Key 3x10mm
Tea Lifter Arm

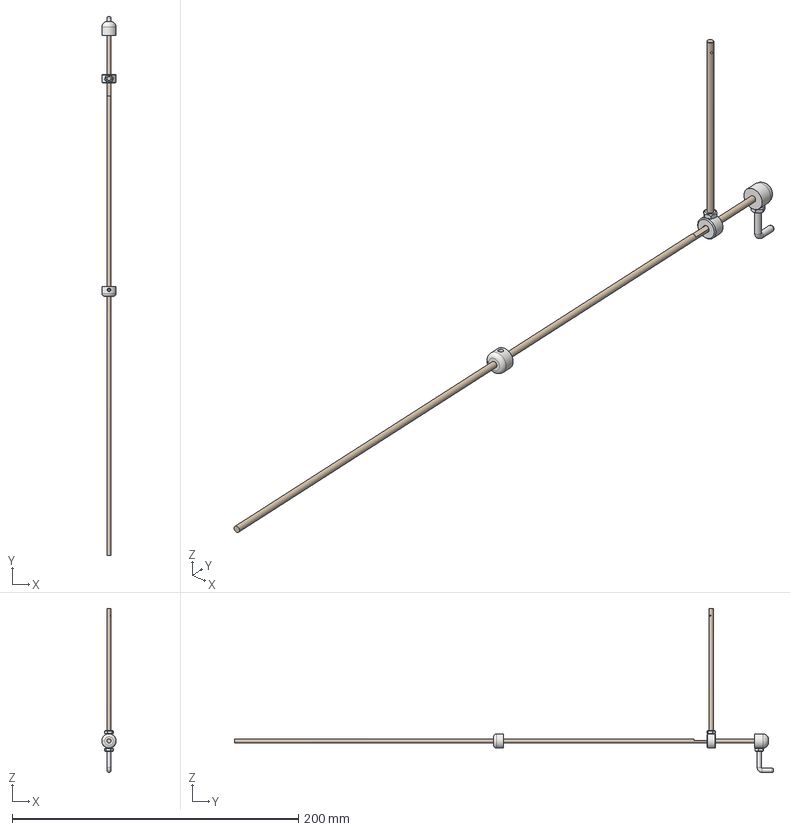
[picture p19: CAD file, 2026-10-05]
CAD/Workspace/Rotating Assembly.stp
10.0 x 376.5 x 114.5 mm
Rotating Rod 370mm
Top Lock Cap
Lock Handel
Pendulum Arm Cap
Pendulum Arm
M3 Hex Nut x 2
Lower Lock Cap
Grub Screw 3x3mm

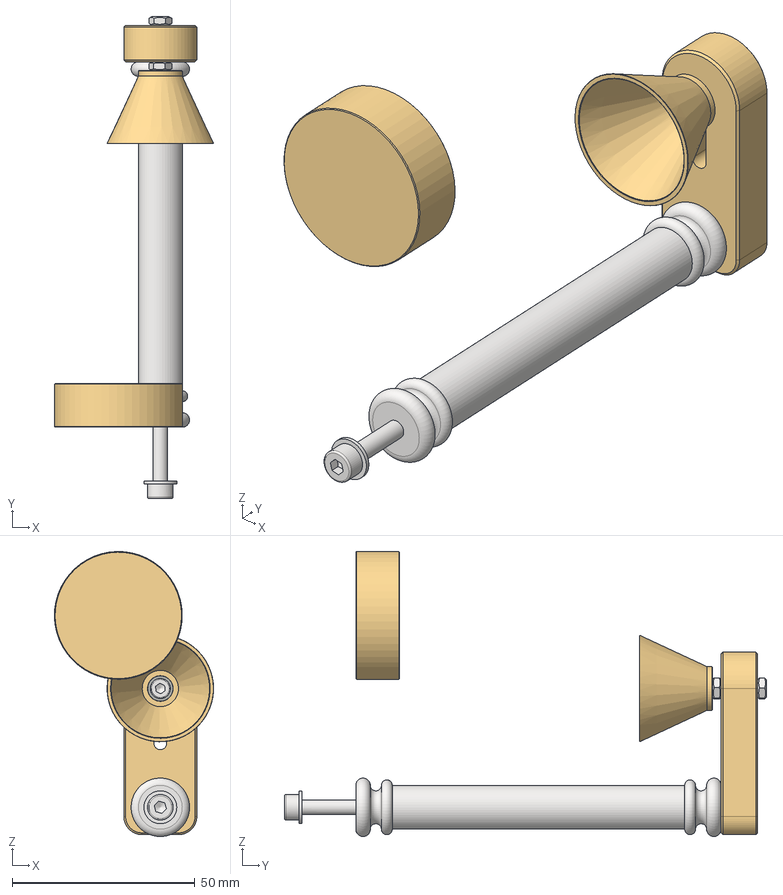
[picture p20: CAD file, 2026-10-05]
CAD/Workspace/Steeping Complete Notification Contraption.stp
43.6 x 131.9 x 78.0 mm
Bell Support Beam
Bell
ISO 4762 - M4 x 25
Shallow Dish
Magnet
Foam Pad
4mm Washer
M3 Hex Nut x 2
Allen Key 3x16mm
3mm Rubber Washer
Bell Support Piller
ISO 10642 - M4x20

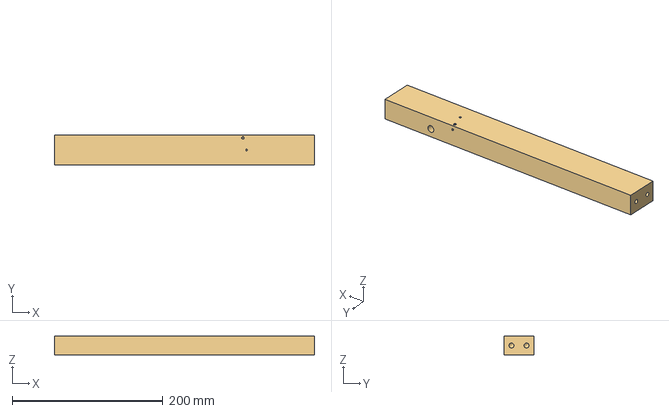
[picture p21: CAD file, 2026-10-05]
CAD/Workspace/Main Piller.stp
345.0 x 40.0 x 25.0 mm

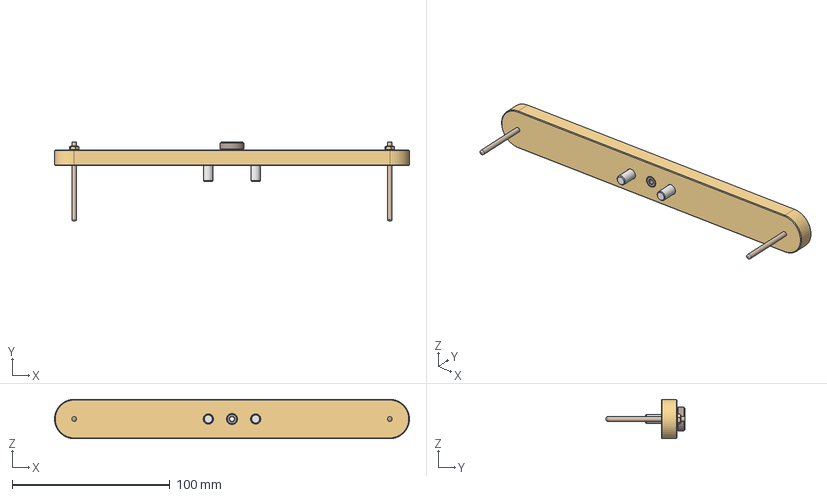
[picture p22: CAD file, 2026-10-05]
CAD/Workspace/Upper Static Arms.stp
225.0 x 50.0 x 25.0 mm
Brass Plate
Bush
Domed End Rod 40mm x 2
Brass M3 Hex Nut x 2
CSK Allen Key 6x20mm x 2

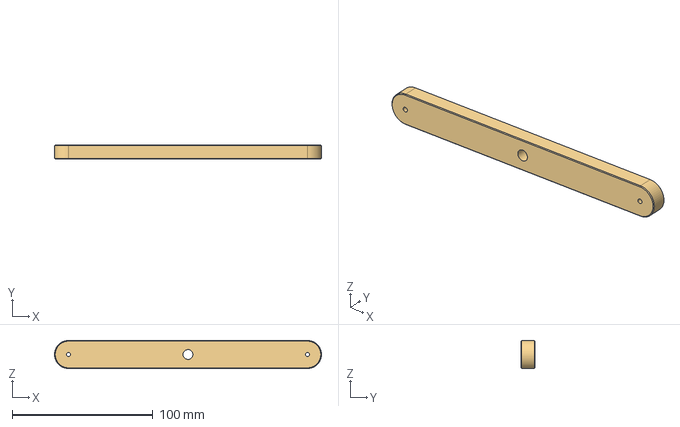
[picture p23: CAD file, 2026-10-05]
CAD/Workspace/Lower Arm Brass Plate - 2.stp
190.0 x 10.0 x 20.0 mm

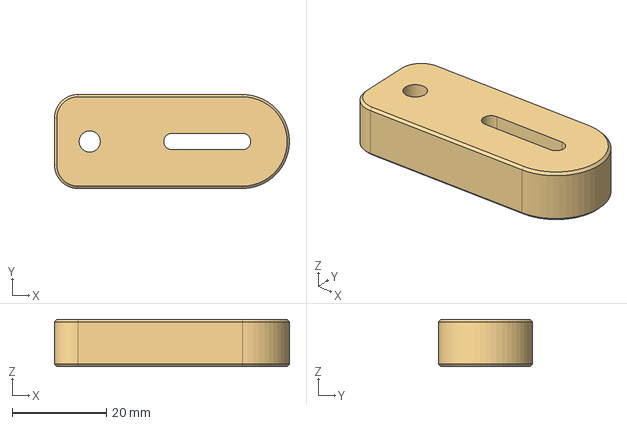
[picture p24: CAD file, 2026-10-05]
CAD/Workspace/Bell Support Beam.stp
50.0 x 20.0 x 10.0 mm

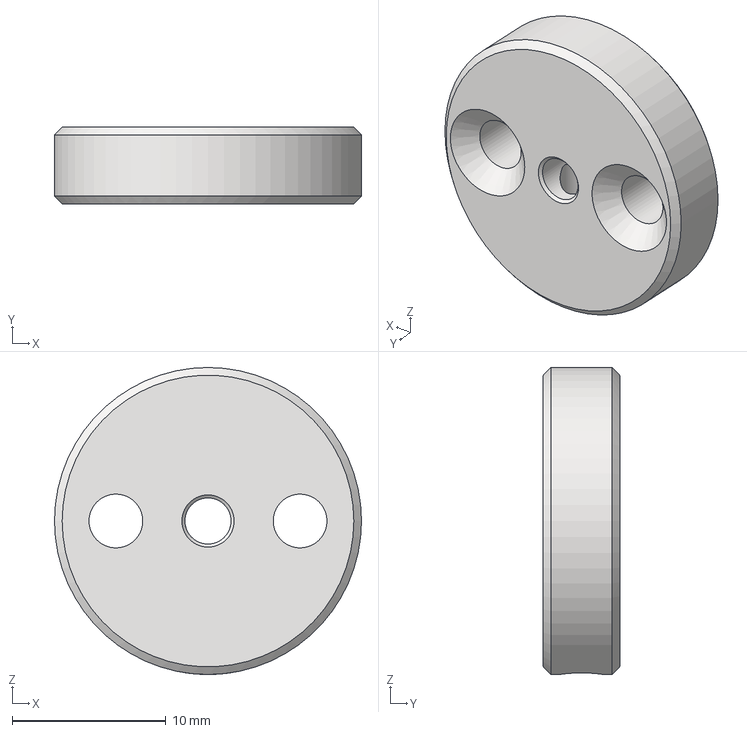
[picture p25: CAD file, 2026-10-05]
CAD/Workspace/Wheel Mounting Cap.stp
20.0 x 5.00 x 20.0 mm

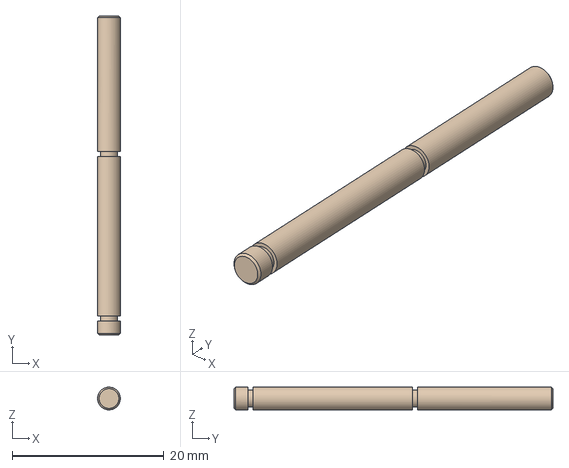
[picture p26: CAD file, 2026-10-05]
CAD/Workspace/Ball Track Support.stp
3.00 x 42.0 x 3.00 mm

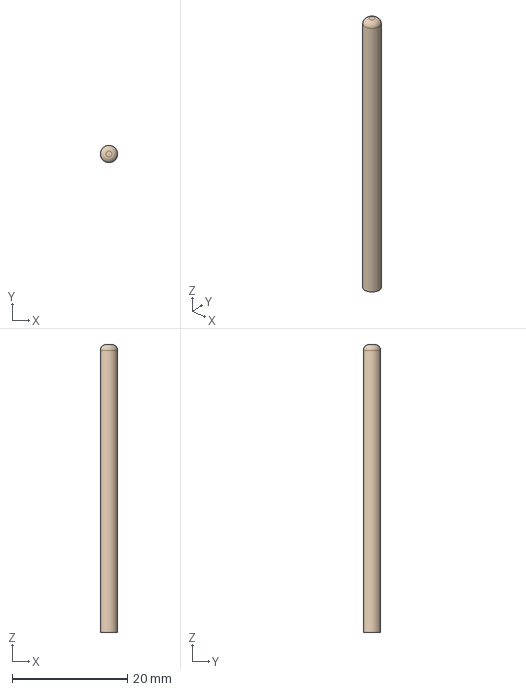
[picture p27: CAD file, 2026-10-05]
CAD/Workspace/Domed End Rod 40mm.stp
3.00 x 3.00 x 50.0 mm

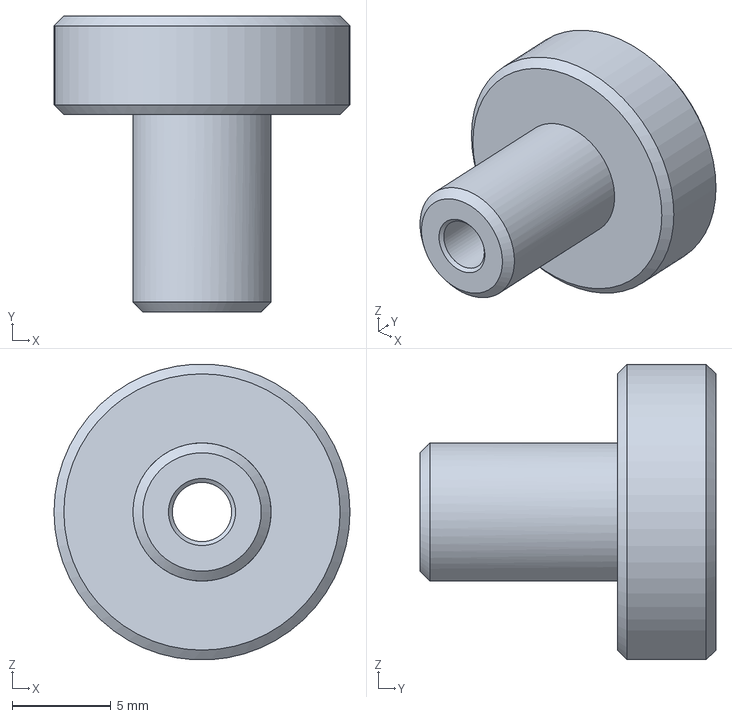
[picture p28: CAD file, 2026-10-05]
CAD/Workspace/Bush.stp
15.0 x 15.0 x 15.0 mm

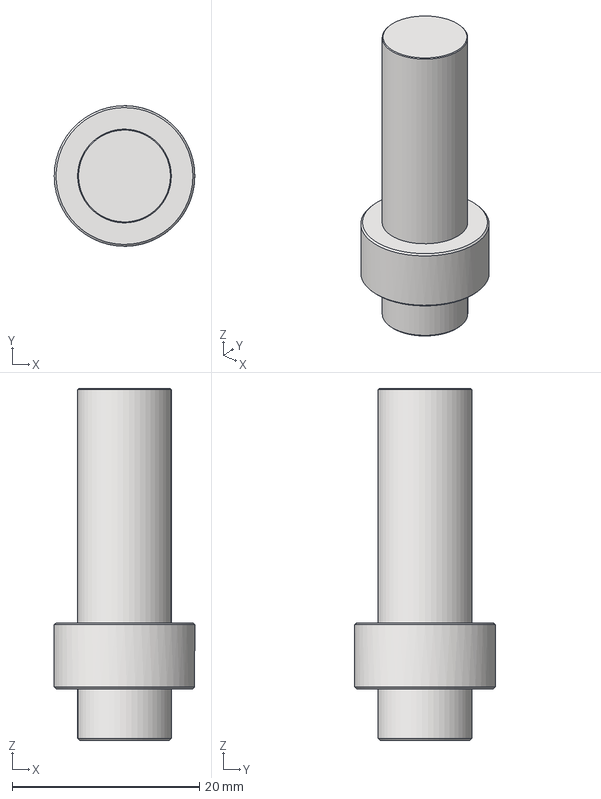
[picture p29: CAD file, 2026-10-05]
CAD/Workspace/Pully Shaft.stp
15.0 x 15.0 x 37.5 mm

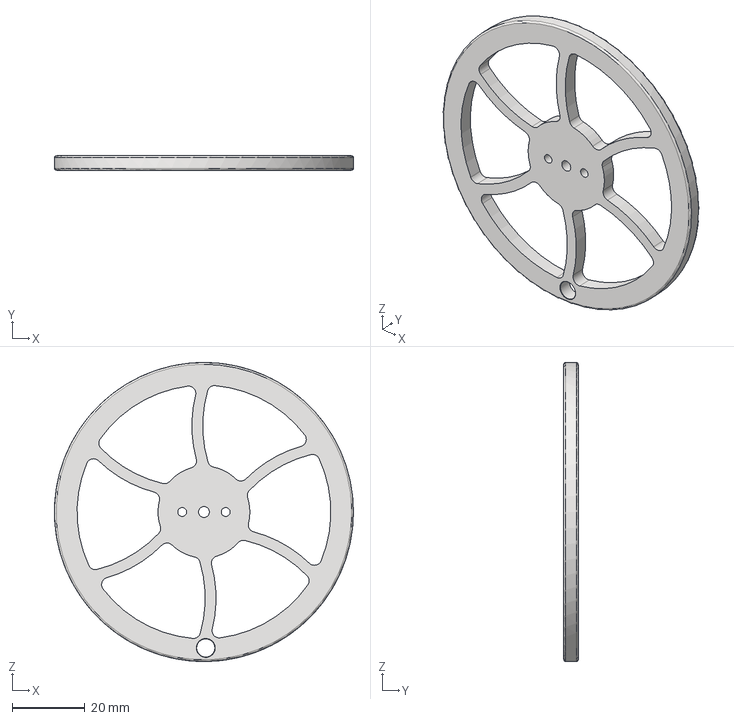
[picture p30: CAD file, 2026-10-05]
CAD/Workspace/Wheel.stp
82.5 x 4.00 x 82.5 mm

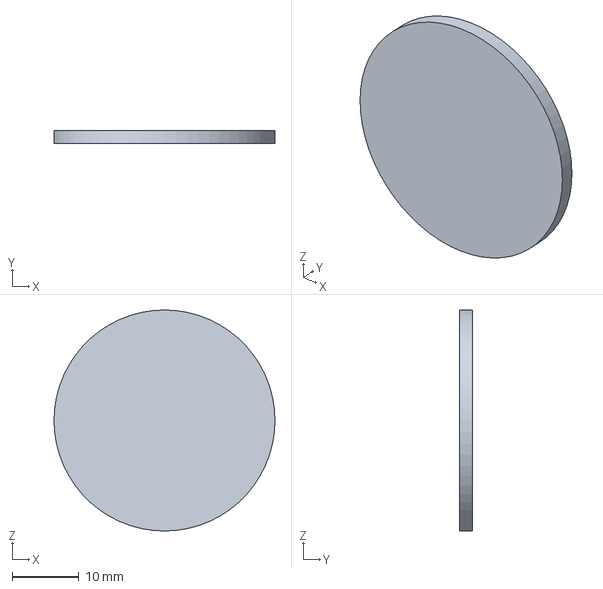
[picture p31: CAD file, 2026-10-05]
CAD/Workspace/Foam Pad.stp
33.0 x 2.00 x 33.0 mm

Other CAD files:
CAD/Workspace/Wheel Shaft Pillar - 2.stp
CAD/Workspace/Lock Handel.stp
CAD/Workspace/Rotating Rod 370mm.stp
CAD/Workspace/Lower Arm Brass Plate.stp
CAD/Workspace/3mm Rubber Washer.dwg
CAD/Workspace/3mm Rubber Washer.ipt
CAD/Workspace/3mm Rubber Washer.stp
CAD/Workspace/4mm Washer.dwg
CAD/Workspace/4mm Washer.ipt
CAD/Workspace/6mm Washer.dwg
CAD/Workspace/6mm Washer.ipt
CAD/Workspace/6mm Washer.stp
CAD/Workspace/Automatic Tea Steeping mechanism.dwg
CAD/Workspace/Automatic Tea Steeping mechanism.iam
CAD/Workspace/Automatic Tea Steeping mechanism.ipn
CAD/Workspace/Automatic Tea Steeping mechanism.stp
CAD/Workspace/Ball Bearing-1.ipt
CAD/Workspace/Ball Bearing-1.stp
CAD/Workspace/Ball Track Mounting Plate.dwg
CAD/Workspace/Ball Track Mounting Plate.ipt
CAD/Workspace/Ball Track Mounting Plate.stp
CAD/Workspace/Ball Track Rest Pin.dwg
CAD/Workspace/Ball Track Rest Pin.ipt
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

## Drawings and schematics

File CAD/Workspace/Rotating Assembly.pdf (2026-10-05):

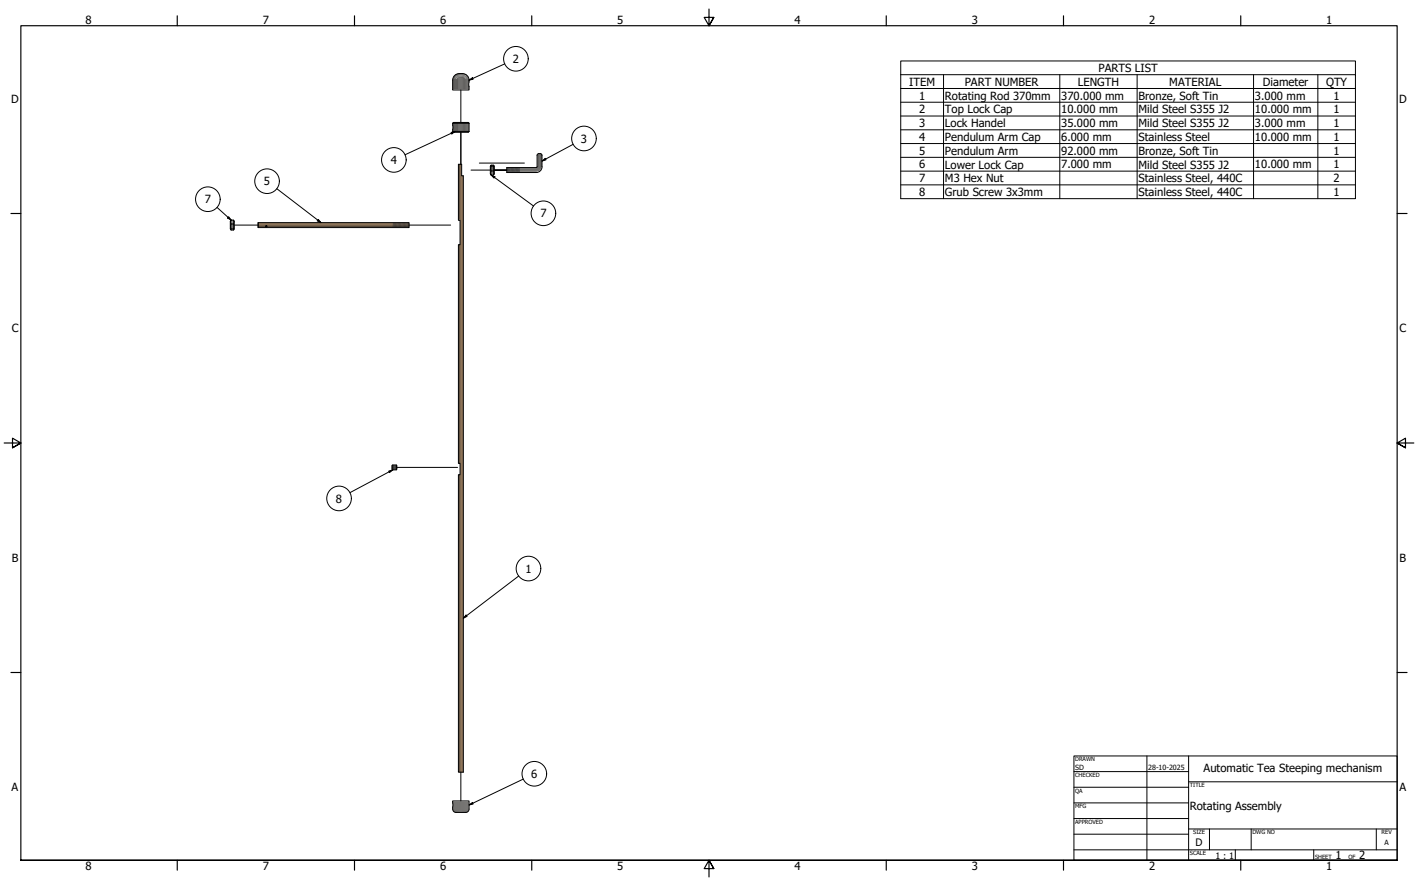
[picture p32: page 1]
PARTS LIST; Rotating Assembly

ITEM | PART NUMBER | LENGTH | MATERIAL | Diameter | QTY
1 | Rotating Rod 370mm | 370.000 mm | Bronze, Soft Tin | 3.000 mm | 1
2 | Top Lock Cap | 10.000 mm | Mild Steel S355 J2 | 10.000 mm | 1
3 | Lock Handel | 35.000 mm | Mild Steel S355 J2 | 3.000 mm | 1
4 | Pendulum Arm Cap | 6.000 mm | Stainless Steel | 10.000 mm | 1
5 | Pendulum Arm | 92.000 mm | Bronze, Soft Tin | | 1
6 | Lower Lock Cap | 7.000 mm | Mild Steel S355 J2 | 10.000 mm | 1
7 | M3 Hex Nut | | Stainless Steel, 440C | | 2
8 | Grub Screw 3x3mm | | Stainless Steel, 440C | | 1

DRAWN SD | 28-10-2025 | Automatic Tea Steeping mechanism

CHECKED

MFG

APPROVED

SIZE D | DWG NO | REV A

SCALE 1 : 1 | | SHEET 1 OF 2

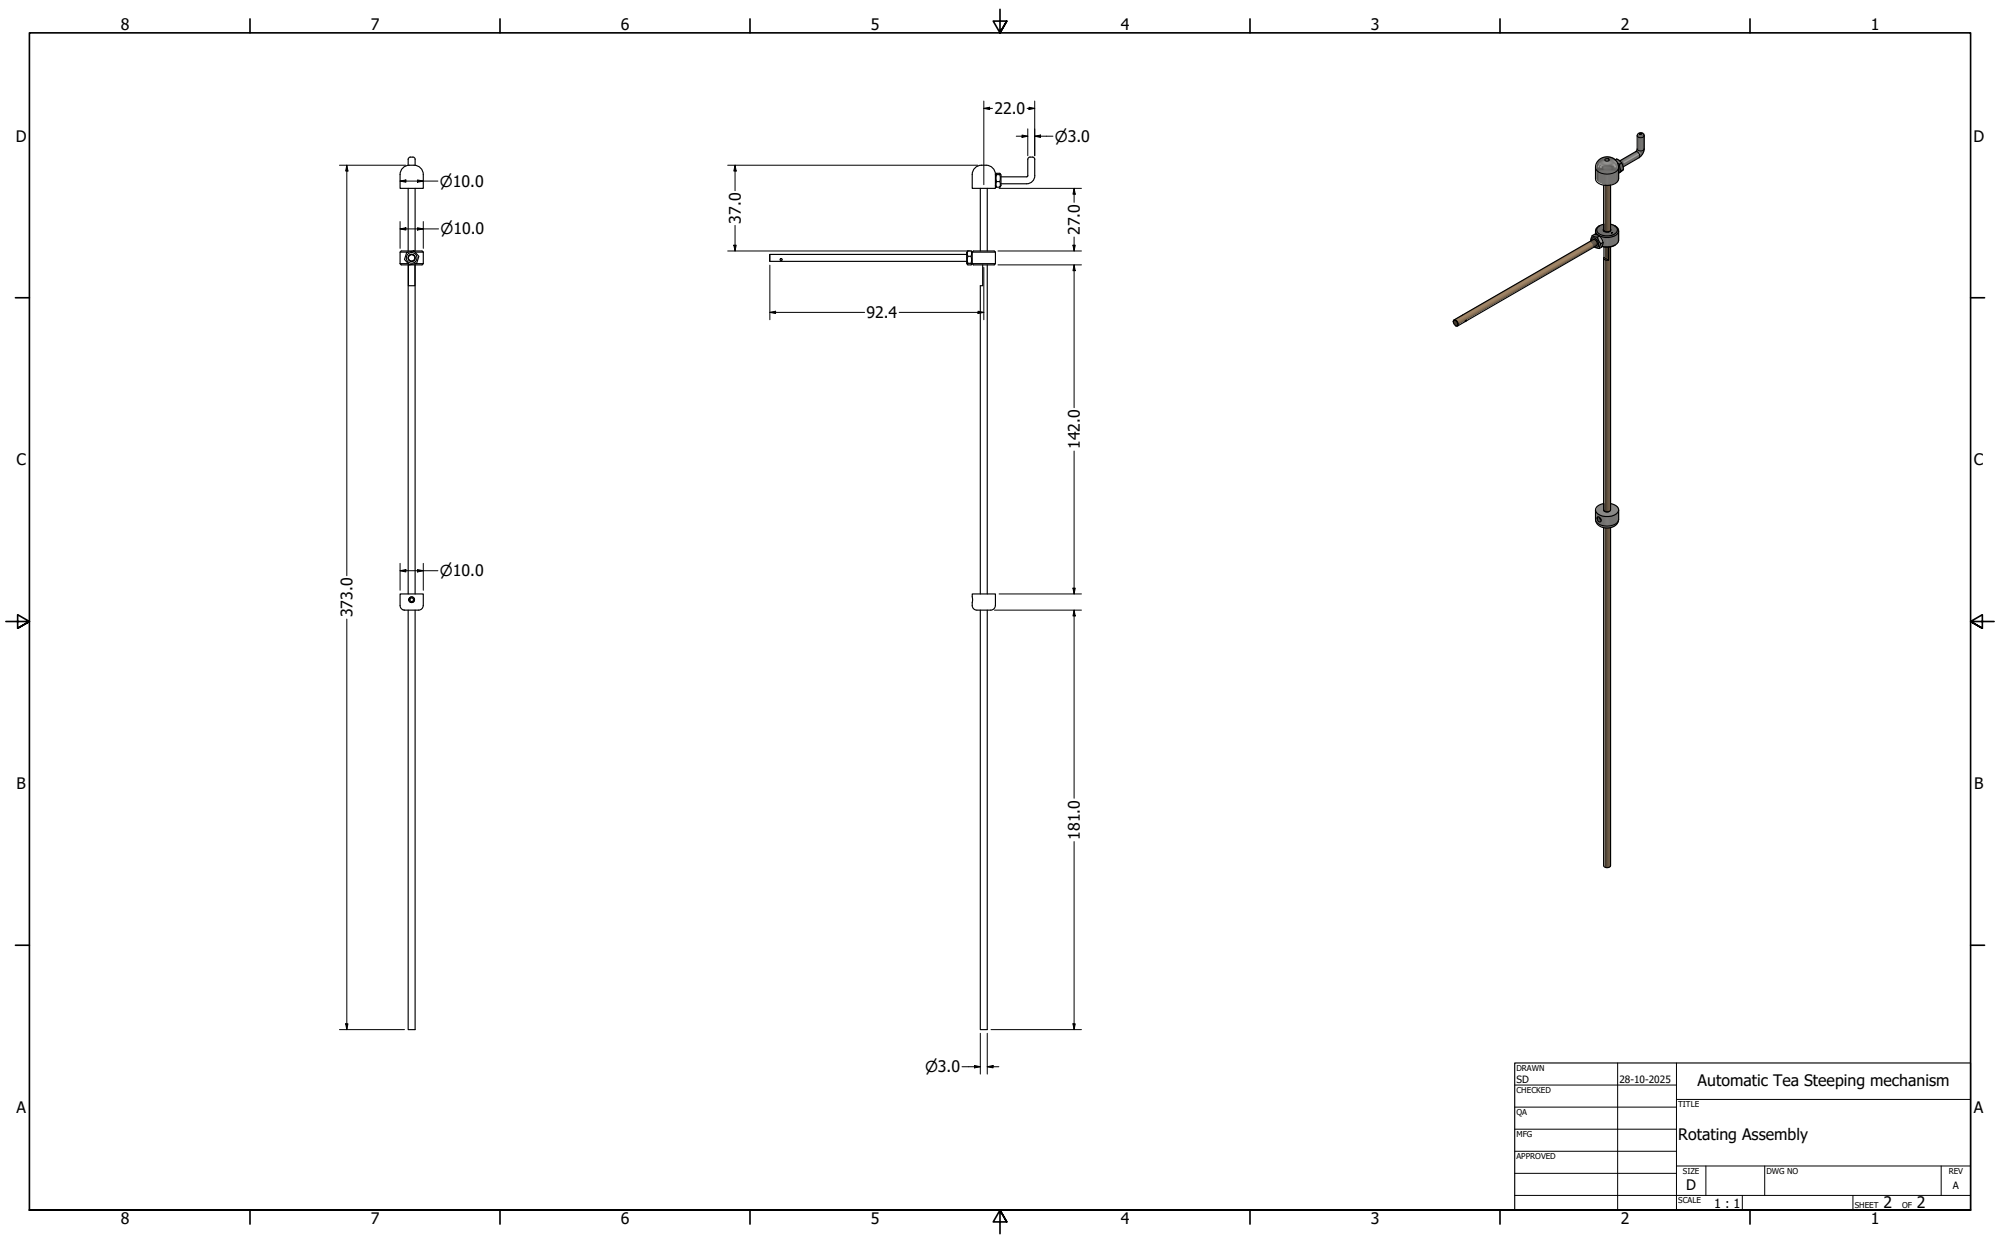
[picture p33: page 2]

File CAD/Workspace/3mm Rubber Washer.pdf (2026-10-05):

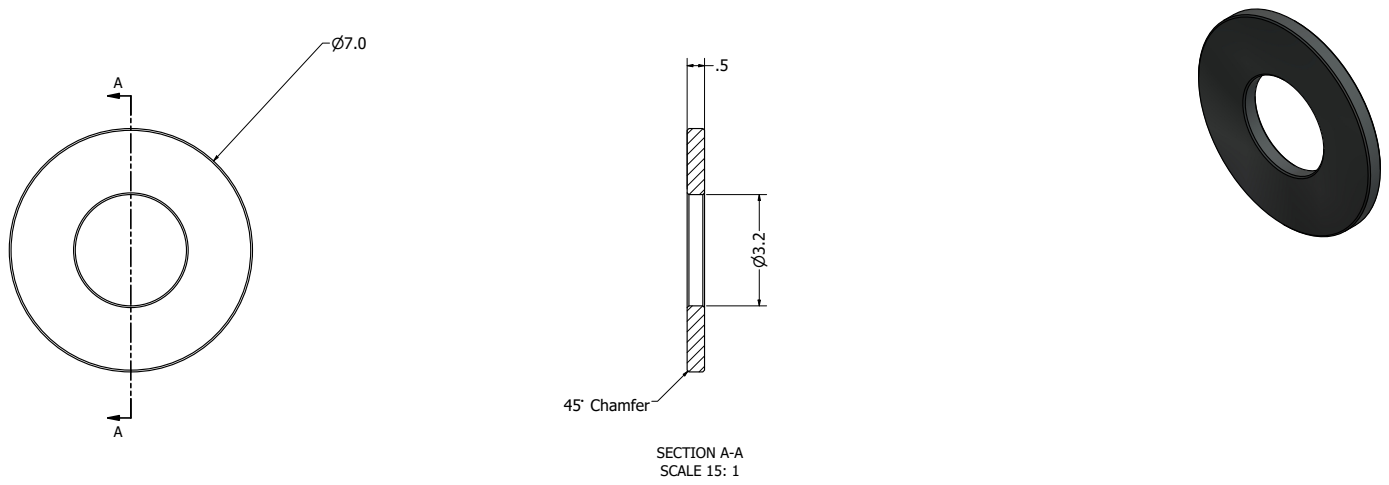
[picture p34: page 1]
SECTION A-A SCALE 15: 1; 3mm Rubber Washer; 45` Chamfer

DRAWN SD | 28-10-2025 | Automatic Tea Steeping mechanism

CHECKED

MFG

APPROVED

SIZE D | DWG NO | REV A

SCALE 15: 1 | | SHEET 1 OF 1

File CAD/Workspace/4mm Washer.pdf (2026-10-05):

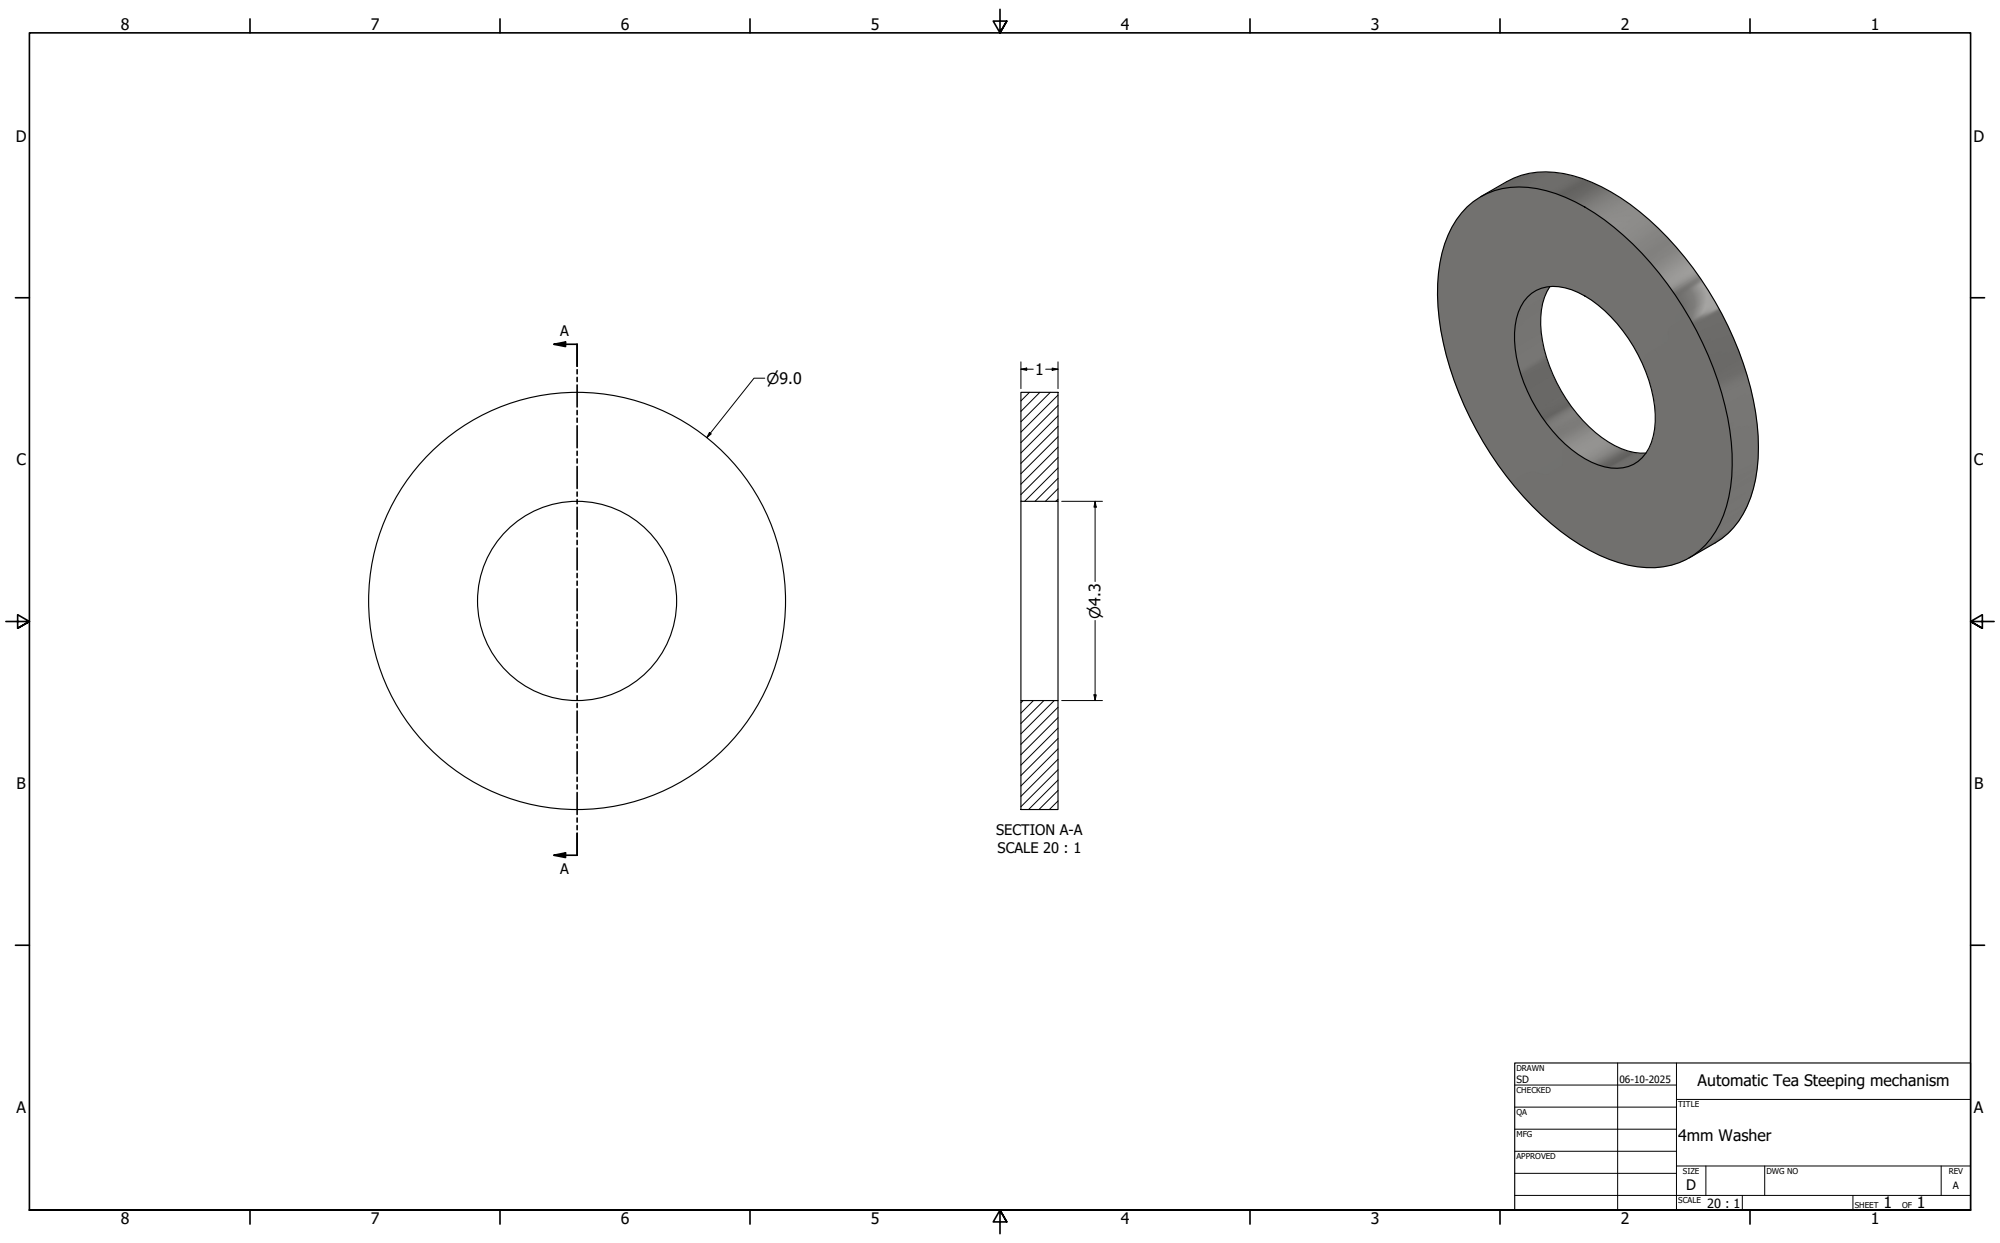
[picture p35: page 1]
SECTION A-A SCALE 20 : 1; 4mm Washer

DRAWN SD | 06-10-2025 | Automatic Tea Steeping mechanism

CHECKED

MFG

APPROVED

SIZE D | DWG NO | REV A

SCALE 20 : 1 | | SHEET 1 OF 1

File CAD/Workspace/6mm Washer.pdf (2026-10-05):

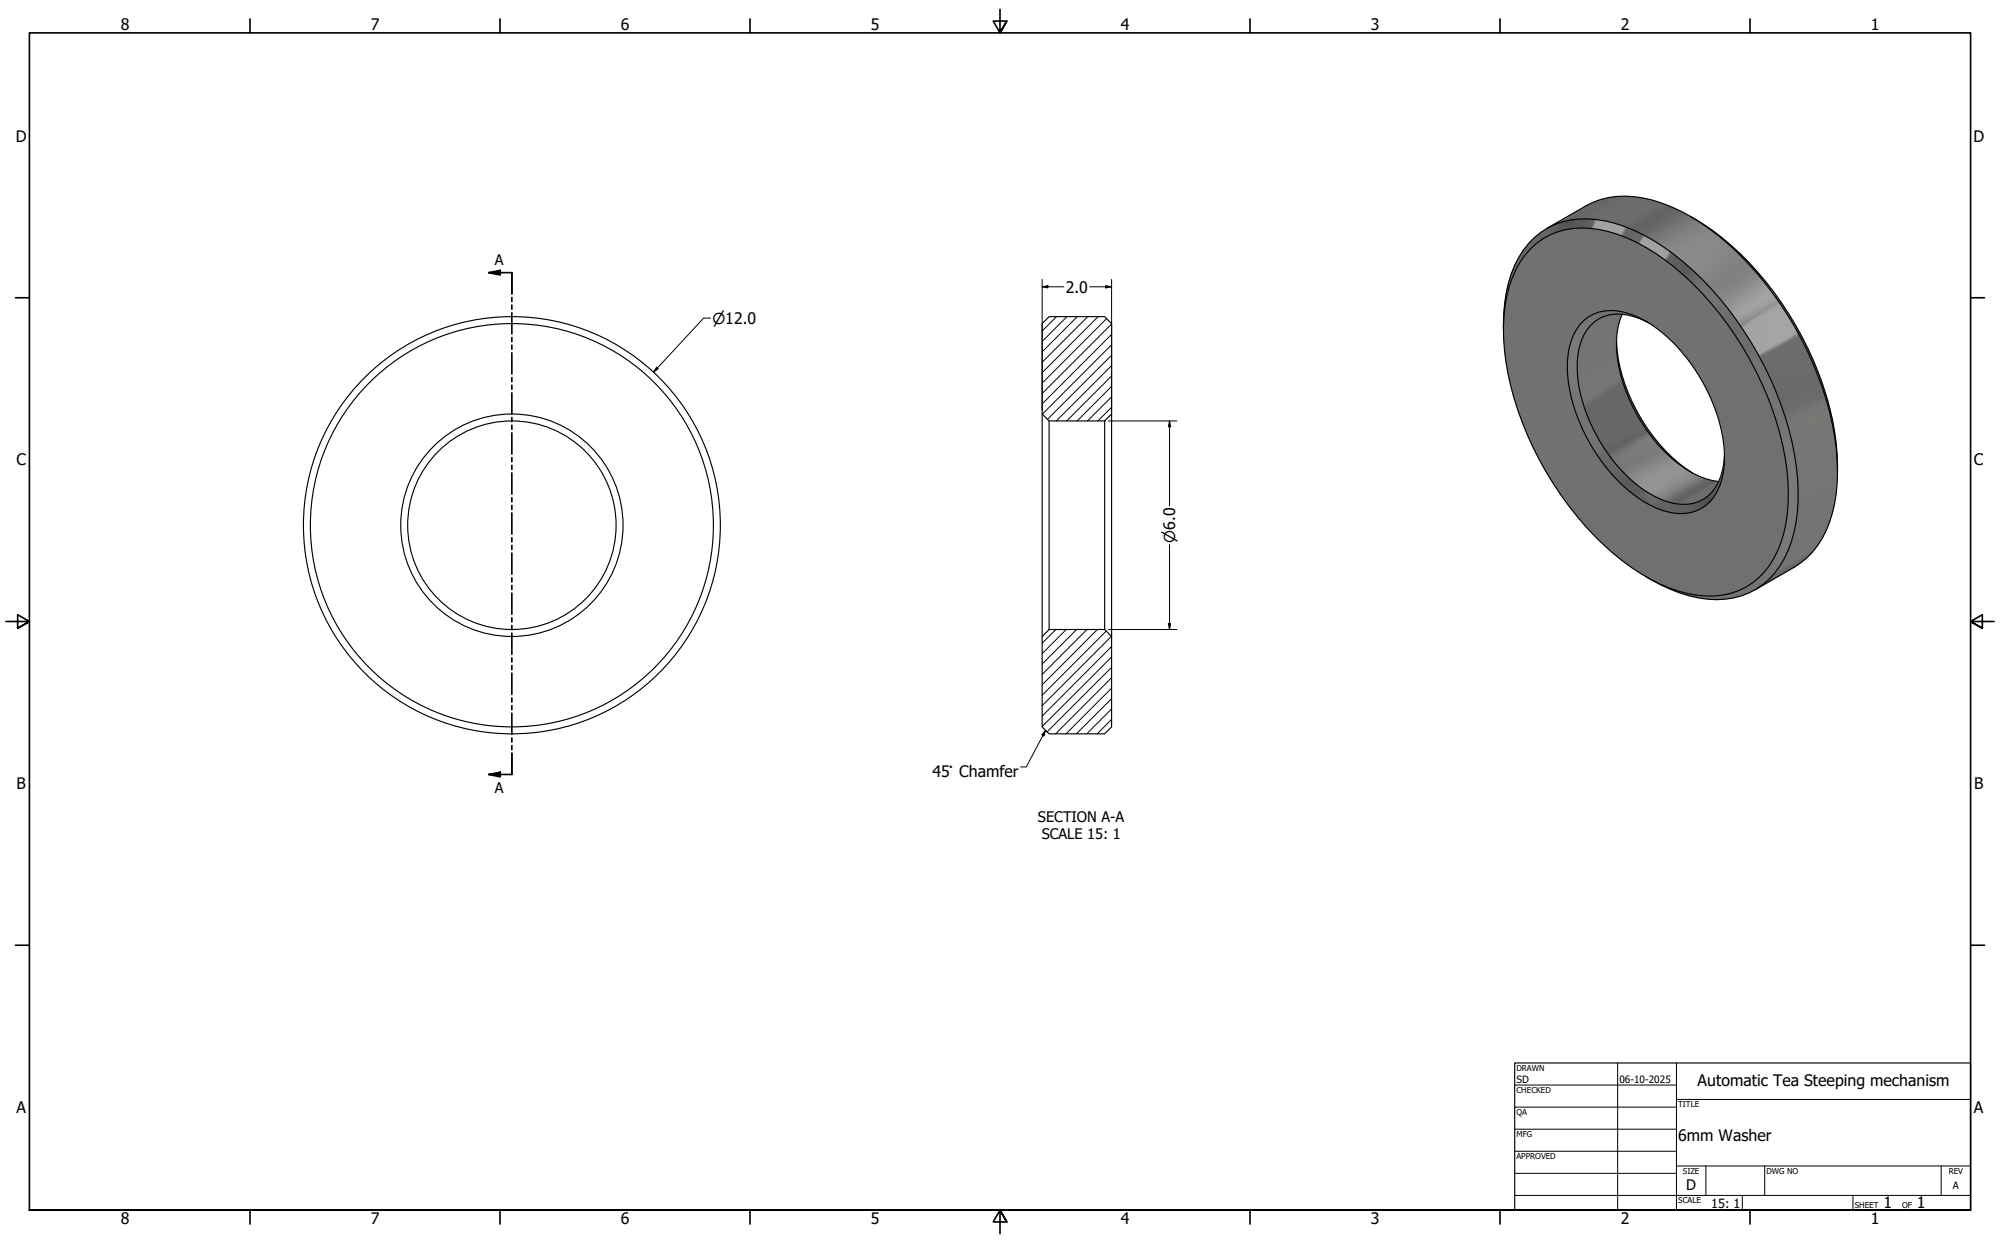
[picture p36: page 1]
SECTION A-A SCALE 15: 1; 6mm Washer; 45` Chamfer

DRAWN SD | 06-10-2025 | Automatic Tea Steeping mechanism

CHECKED

MFG

APPROVED

SIZE D | DWG NO | REV A

SCALE 15: 1 | | SHEET 1 OF 1

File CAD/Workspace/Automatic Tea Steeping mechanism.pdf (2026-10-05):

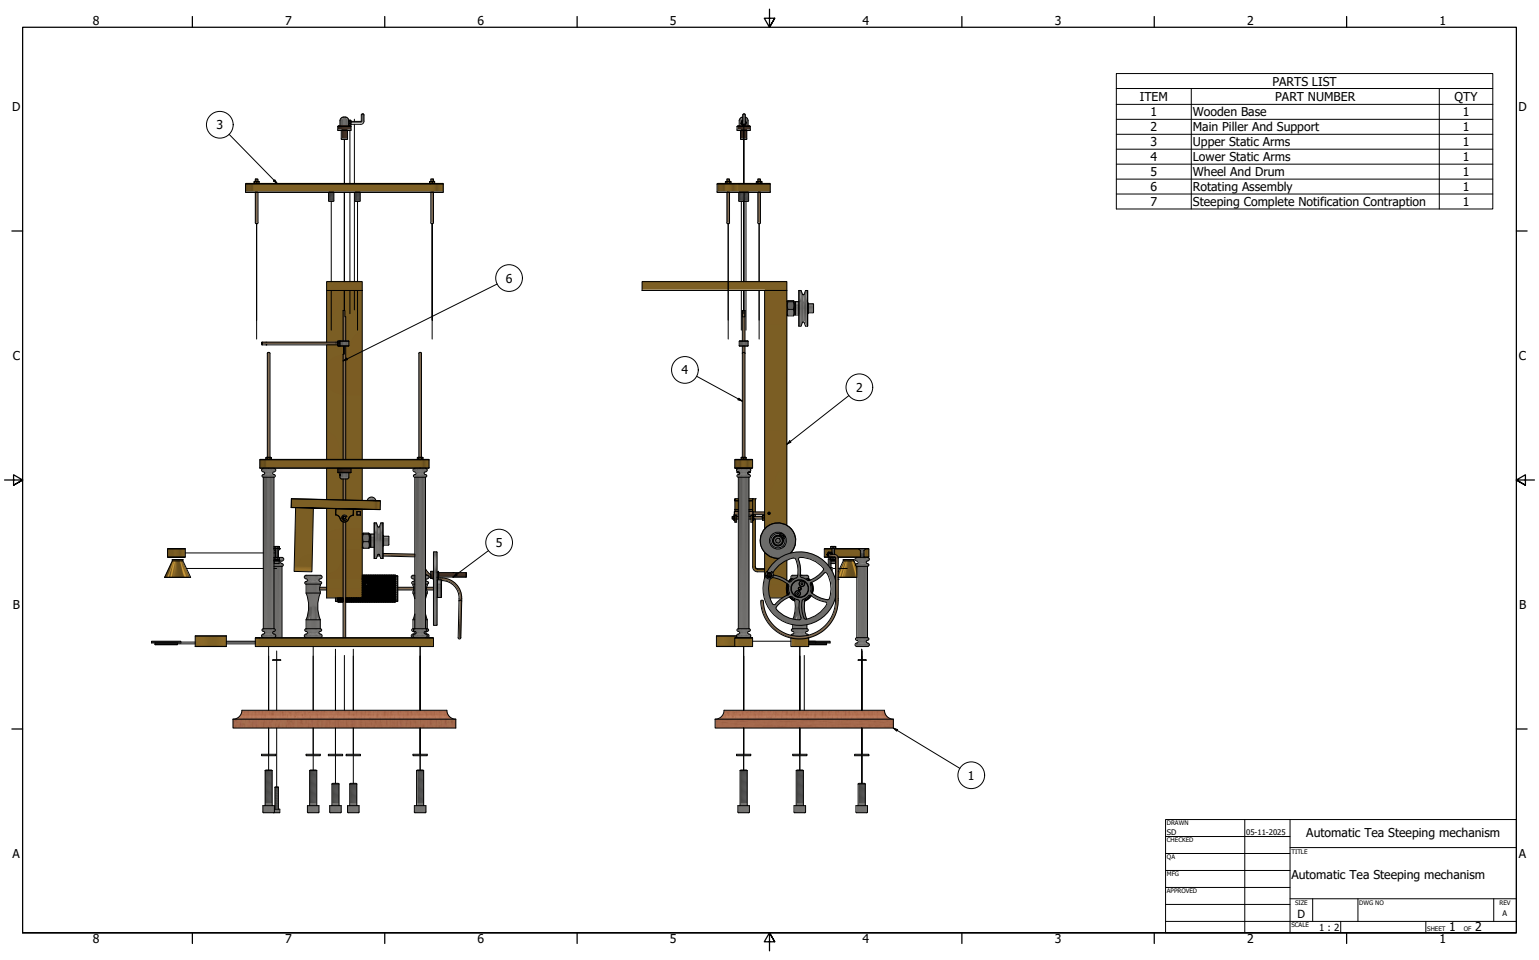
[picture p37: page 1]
PARTS LIST

ITEM | PART NUMBER | QTY
1 | Wooden Base | 1
2 | Main Piller And Support | 1
3 | Upper Static Arms | 1
4 | Lower Static Arms | 1
5 | Wheel And Drum | 1
6 | Rotating Assembly | 1
7 | Steeping Complete Notification Contraption | 1

DRAWN SD | 05-11-2025 | Automatic Tea Steeping mechanism

CHECKED

TITLE
Automatic Tea Steeping mechanism

MFG

APPROVED

SIZE D | DWG NO | REV A

SCALE 1 : 2 | | SHEET 1 OF 2

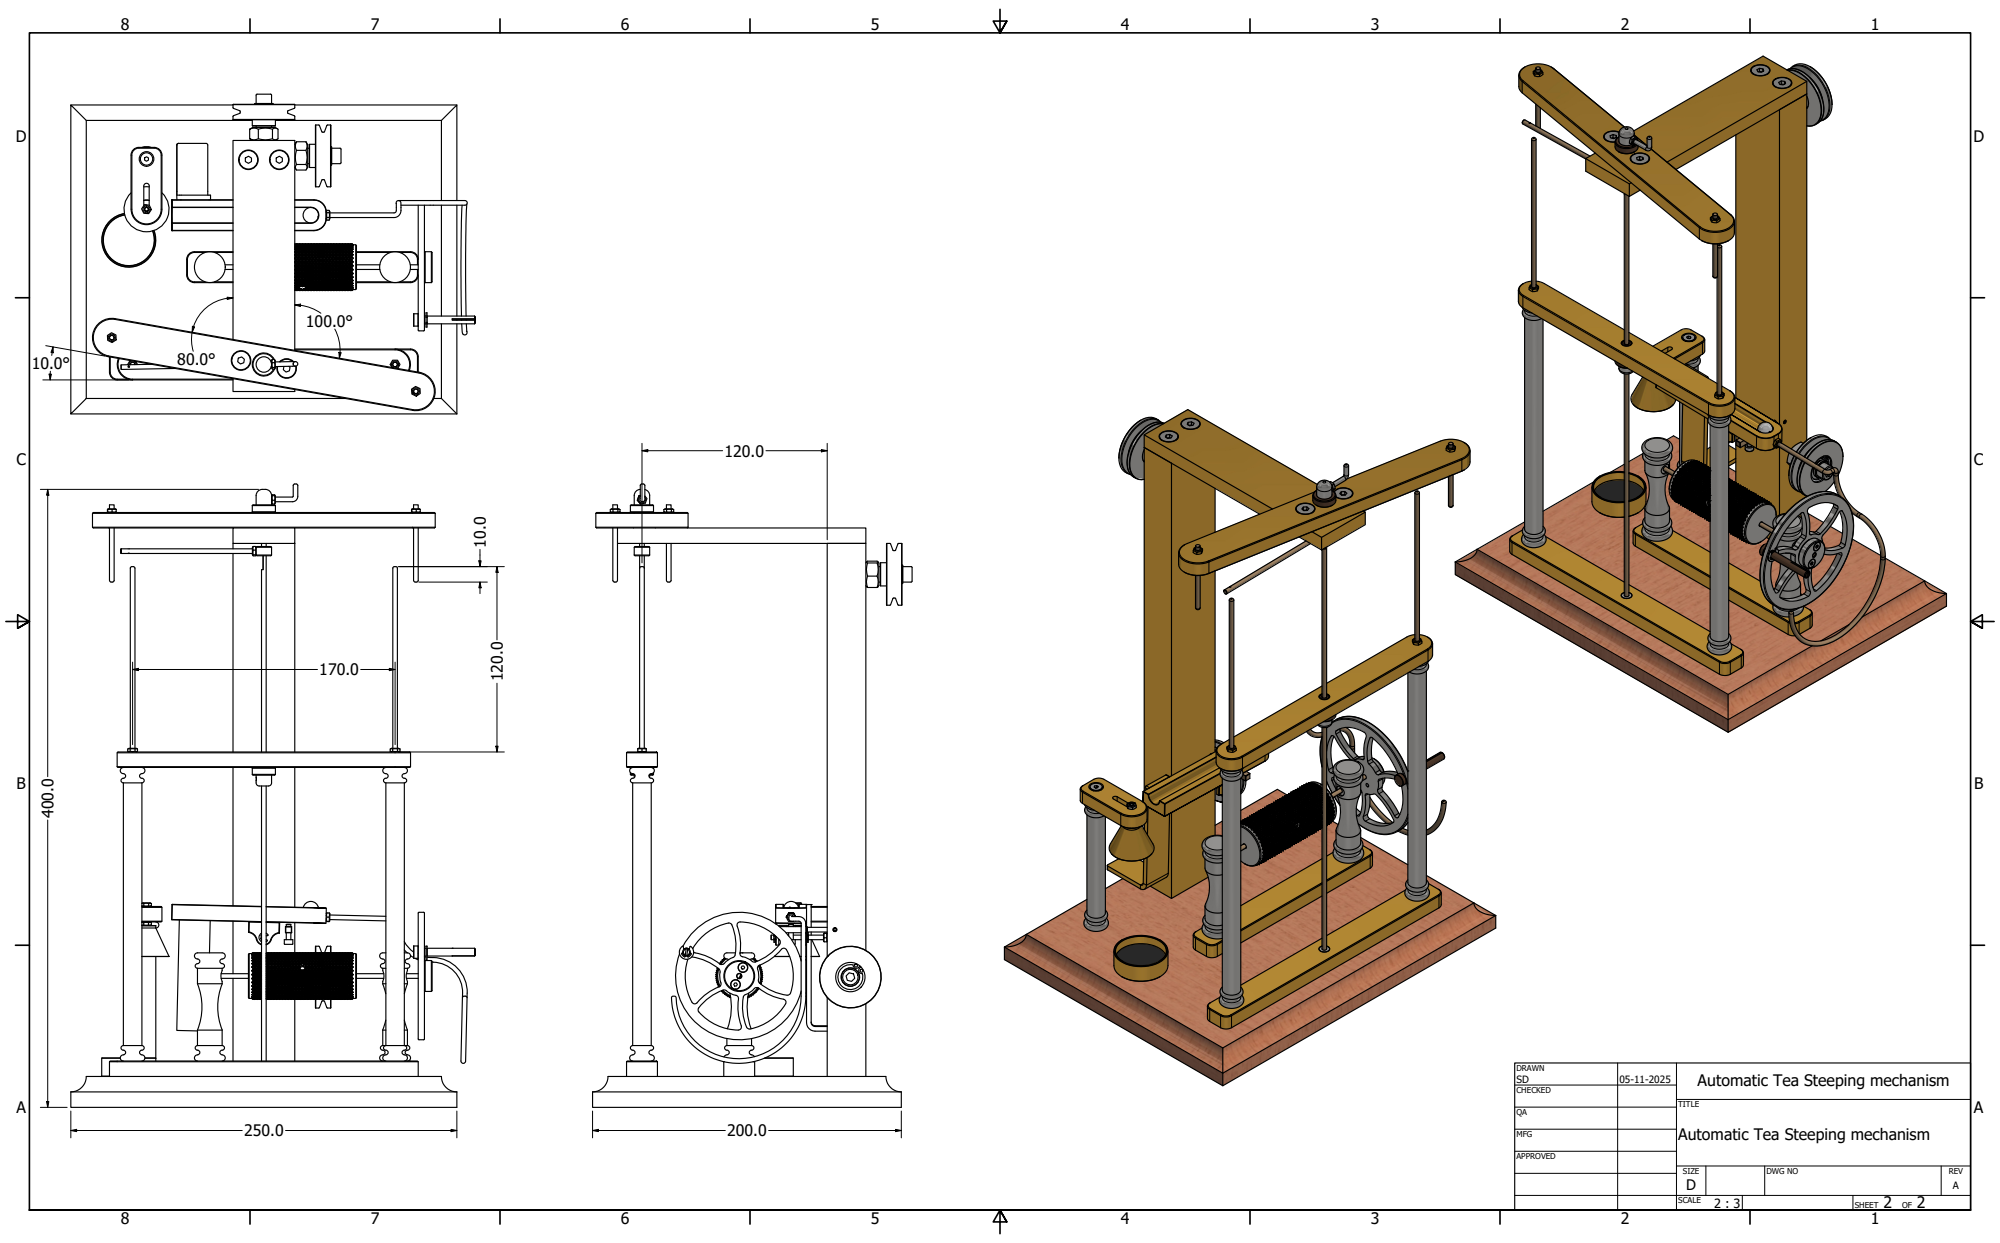
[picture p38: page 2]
SHEET 2 OF 2; DWG NO

Automatic Tea Steeping mechanism

TITLE

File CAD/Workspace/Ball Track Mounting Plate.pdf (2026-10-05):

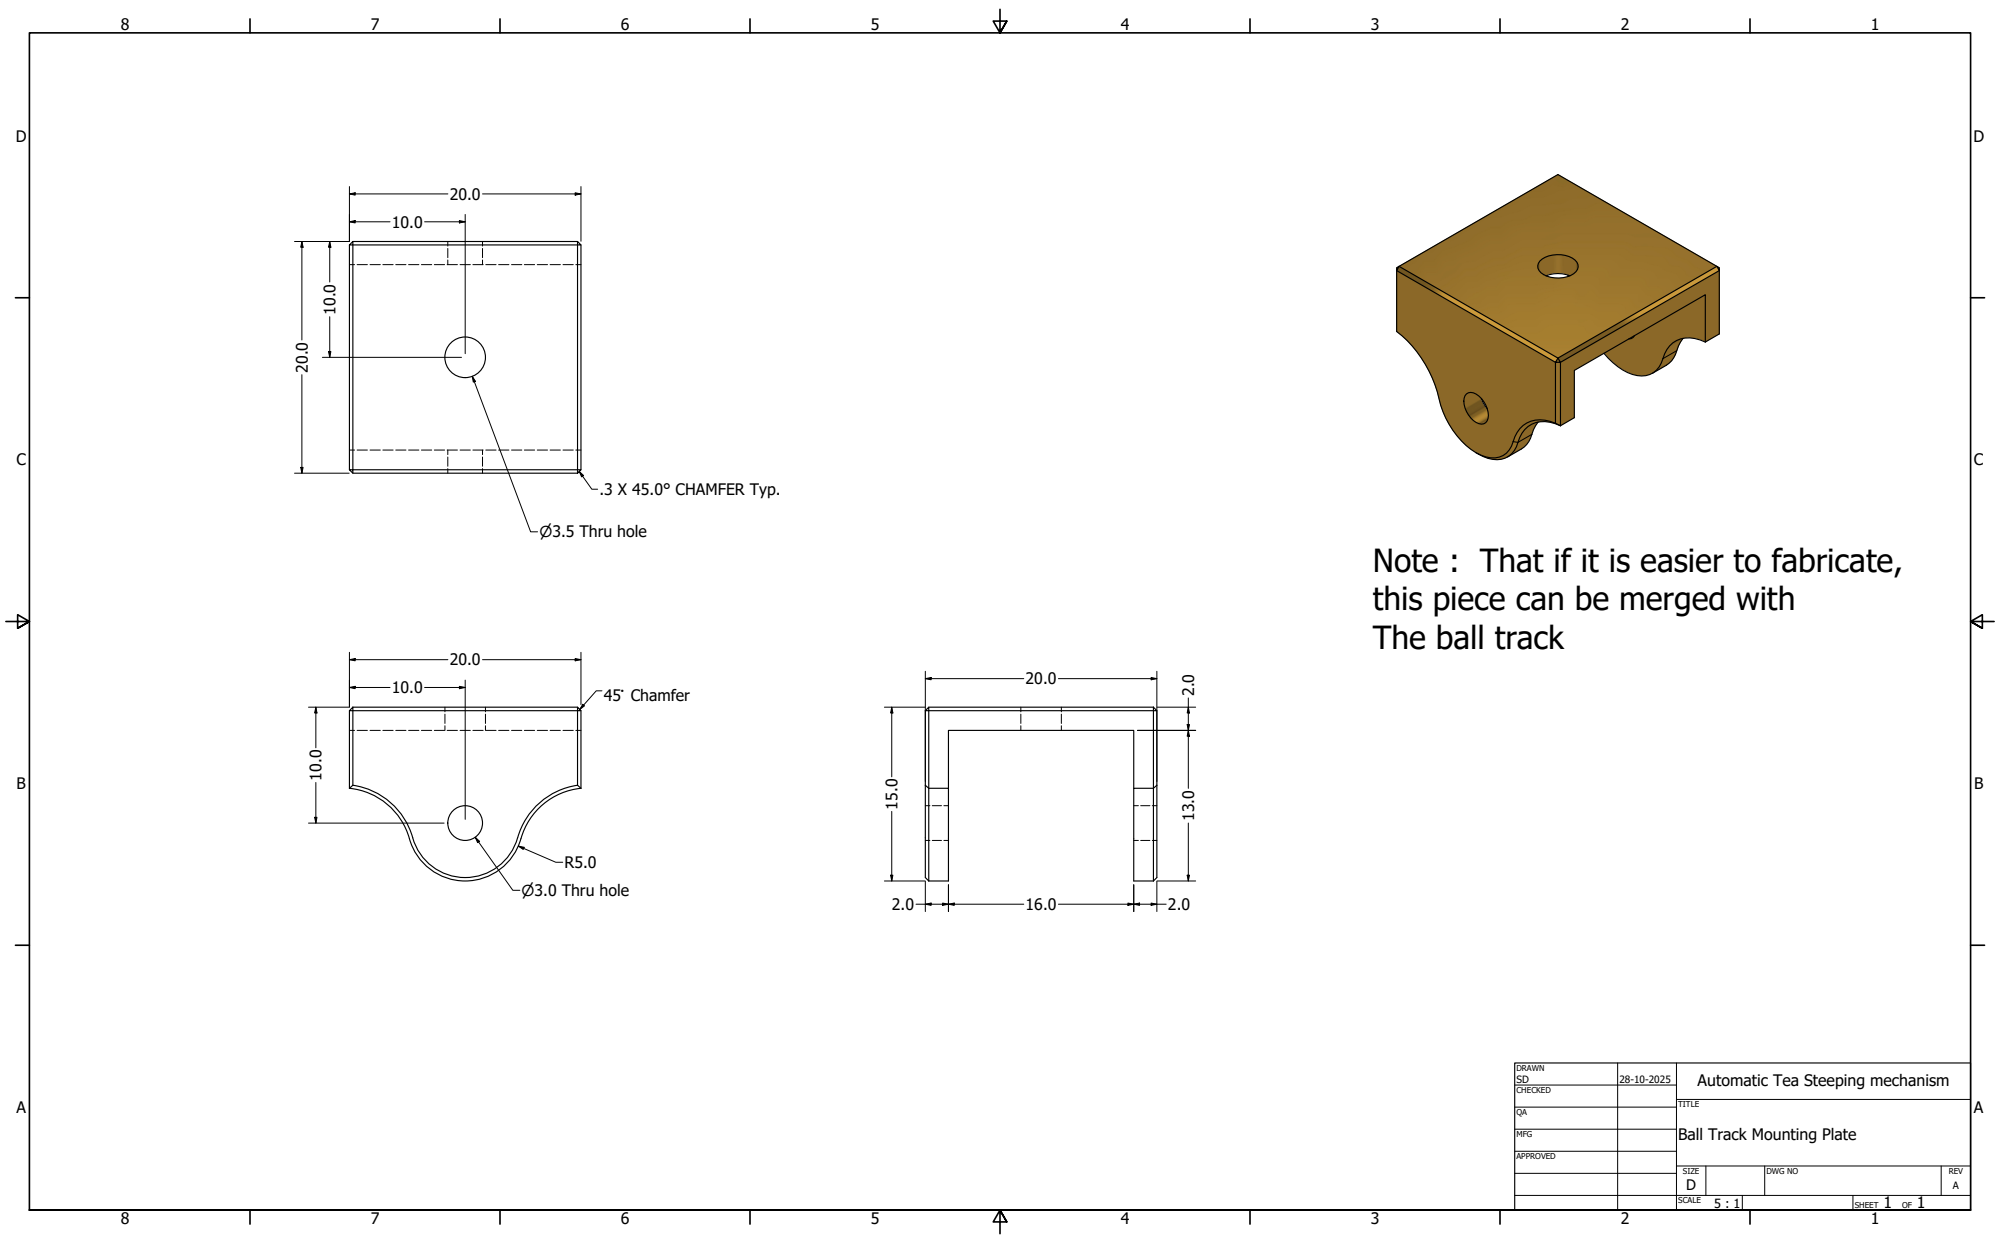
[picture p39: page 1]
45` Chamfer; .3 X 45.0° CHAMFER Typ.

Note : That if it is easier to fabricate,
this piece can be merged with
The ball track

DRAWN SD | 28-10-2025 | Automatic Tea Steeping mechanism

CHECKED

TITLE
Ball Track Mounting Plate

MFG

APPROVED

SIZE D | DWG NO | REV A

SCALE 5 : 1 | | SHEET 1 OF 1

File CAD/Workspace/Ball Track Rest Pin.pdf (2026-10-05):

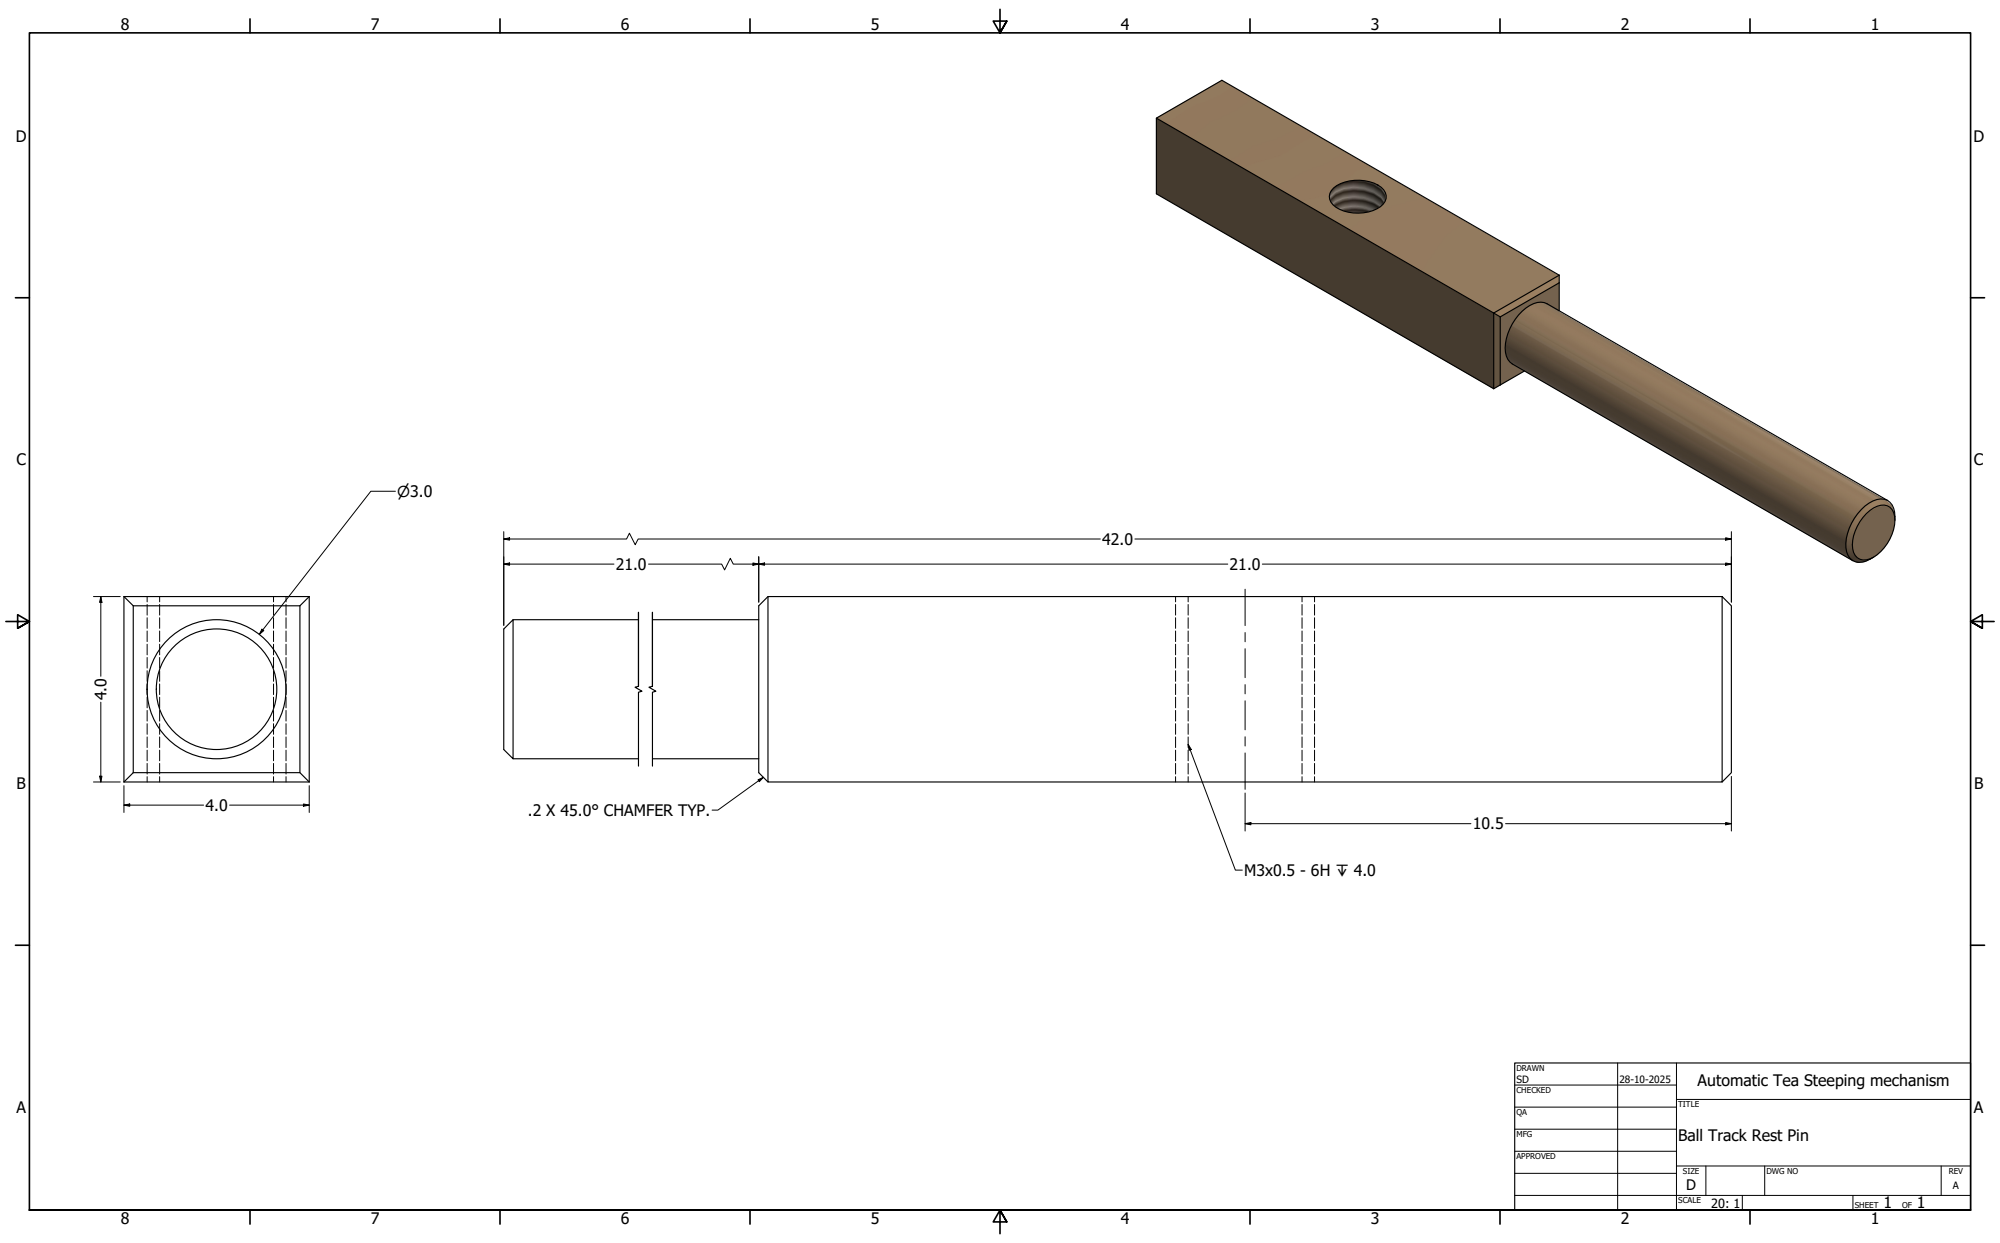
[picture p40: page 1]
.2 X 45.0° CHAMFER TYP.

DRAWN SD | 28-10-2025 | Automatic Tea Steeping mechanism

CHECKED

TITLE
Ball Track Rest Pin

MFG

APPROVED

SIZE D | DWG NO | REV A

SCALE 20: 1 | | SHEET 1 OF 1

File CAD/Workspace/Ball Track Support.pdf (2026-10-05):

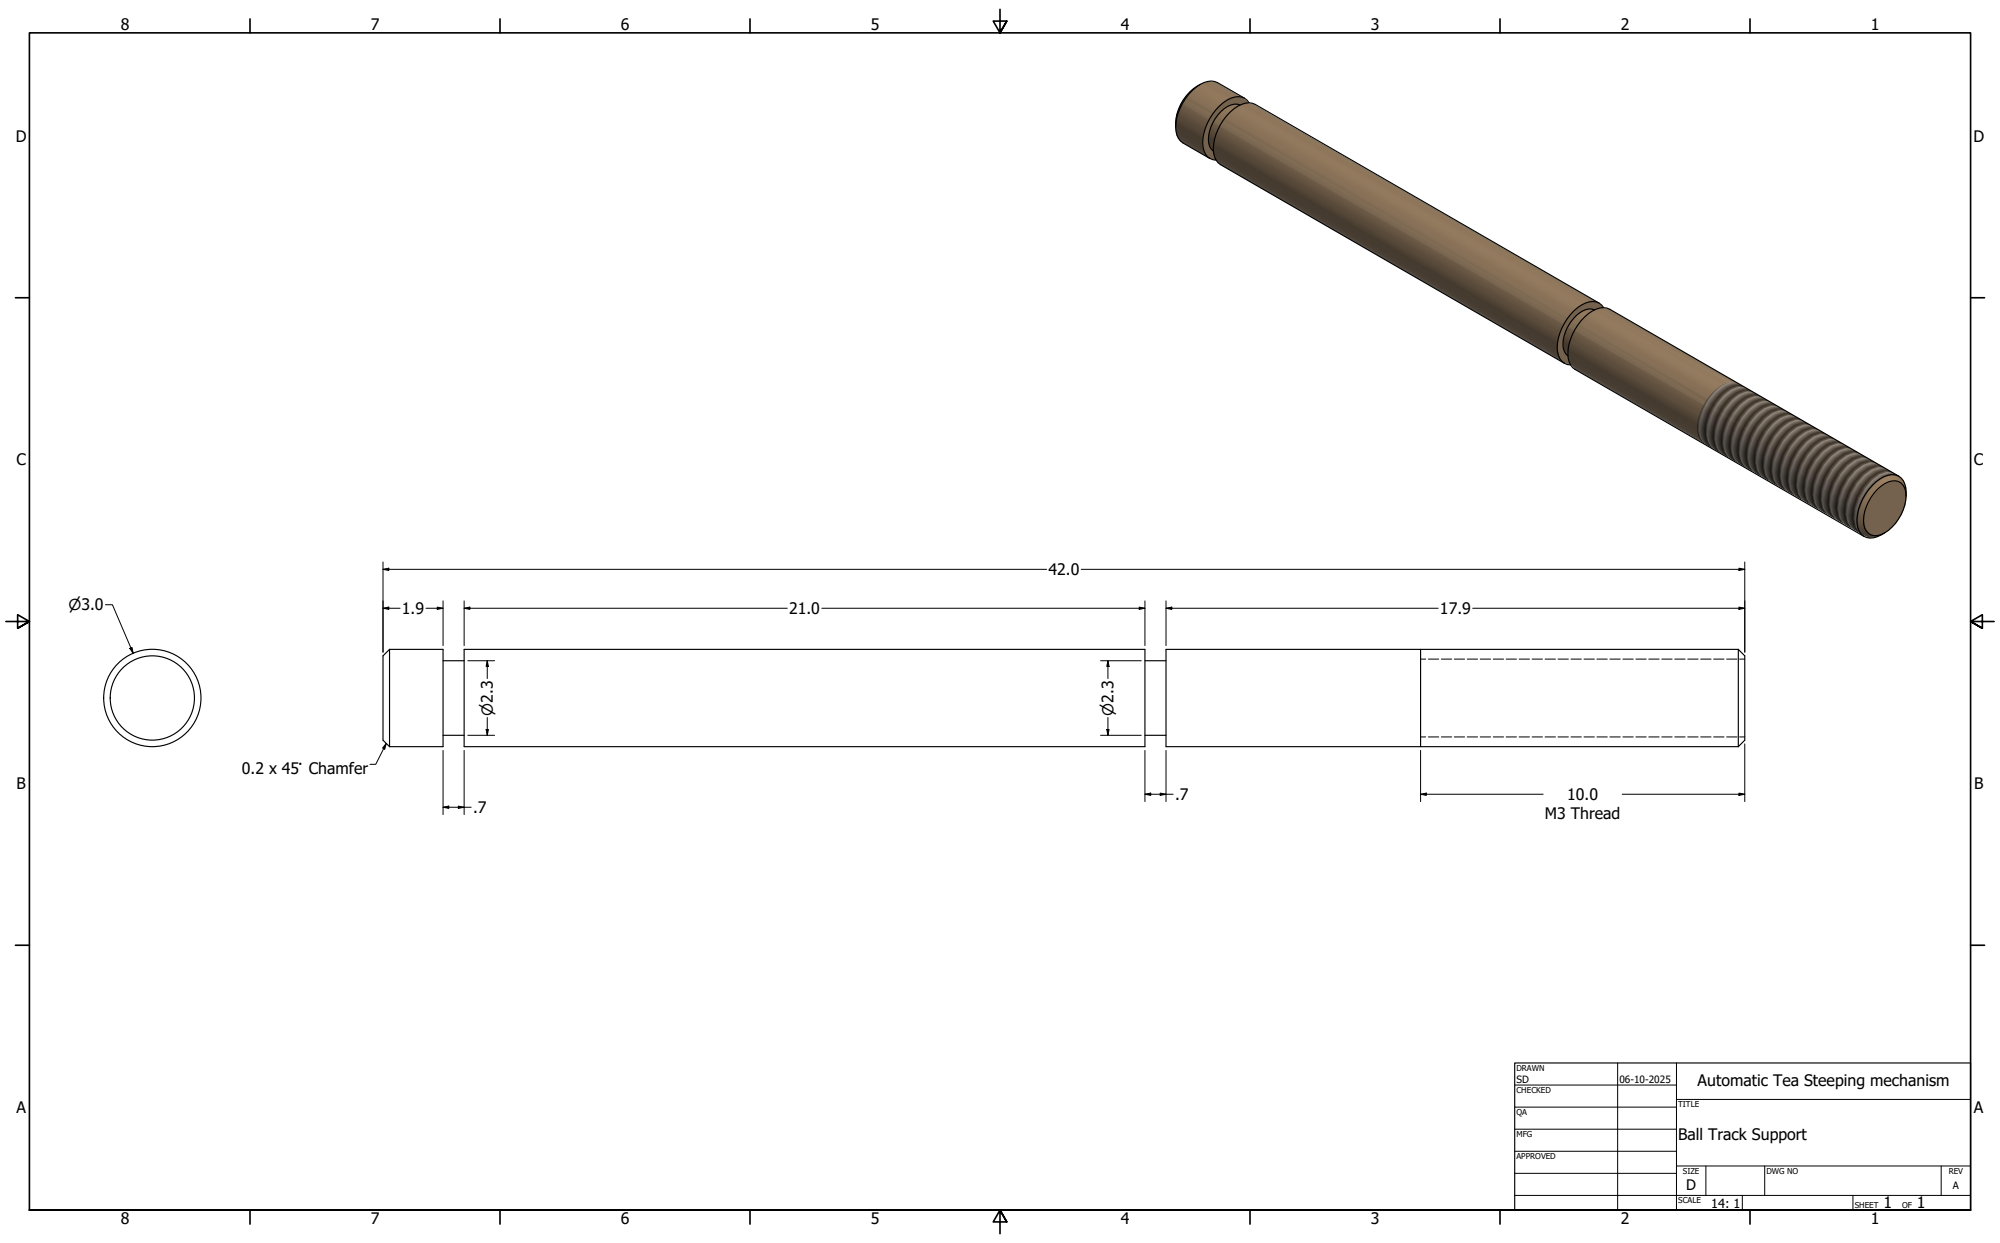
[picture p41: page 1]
M3 Thread; 0.2 x 45` Chamfer

DRAWN SD | 06-10-2025 | Automatic Tea Steeping mechanism

CHECKED

TITLE
Ball Track Support

MFG

APPROVED

SIZE D | DWG NO | REV A

SCALE 14: 1 | | SHEET 1 OF 1

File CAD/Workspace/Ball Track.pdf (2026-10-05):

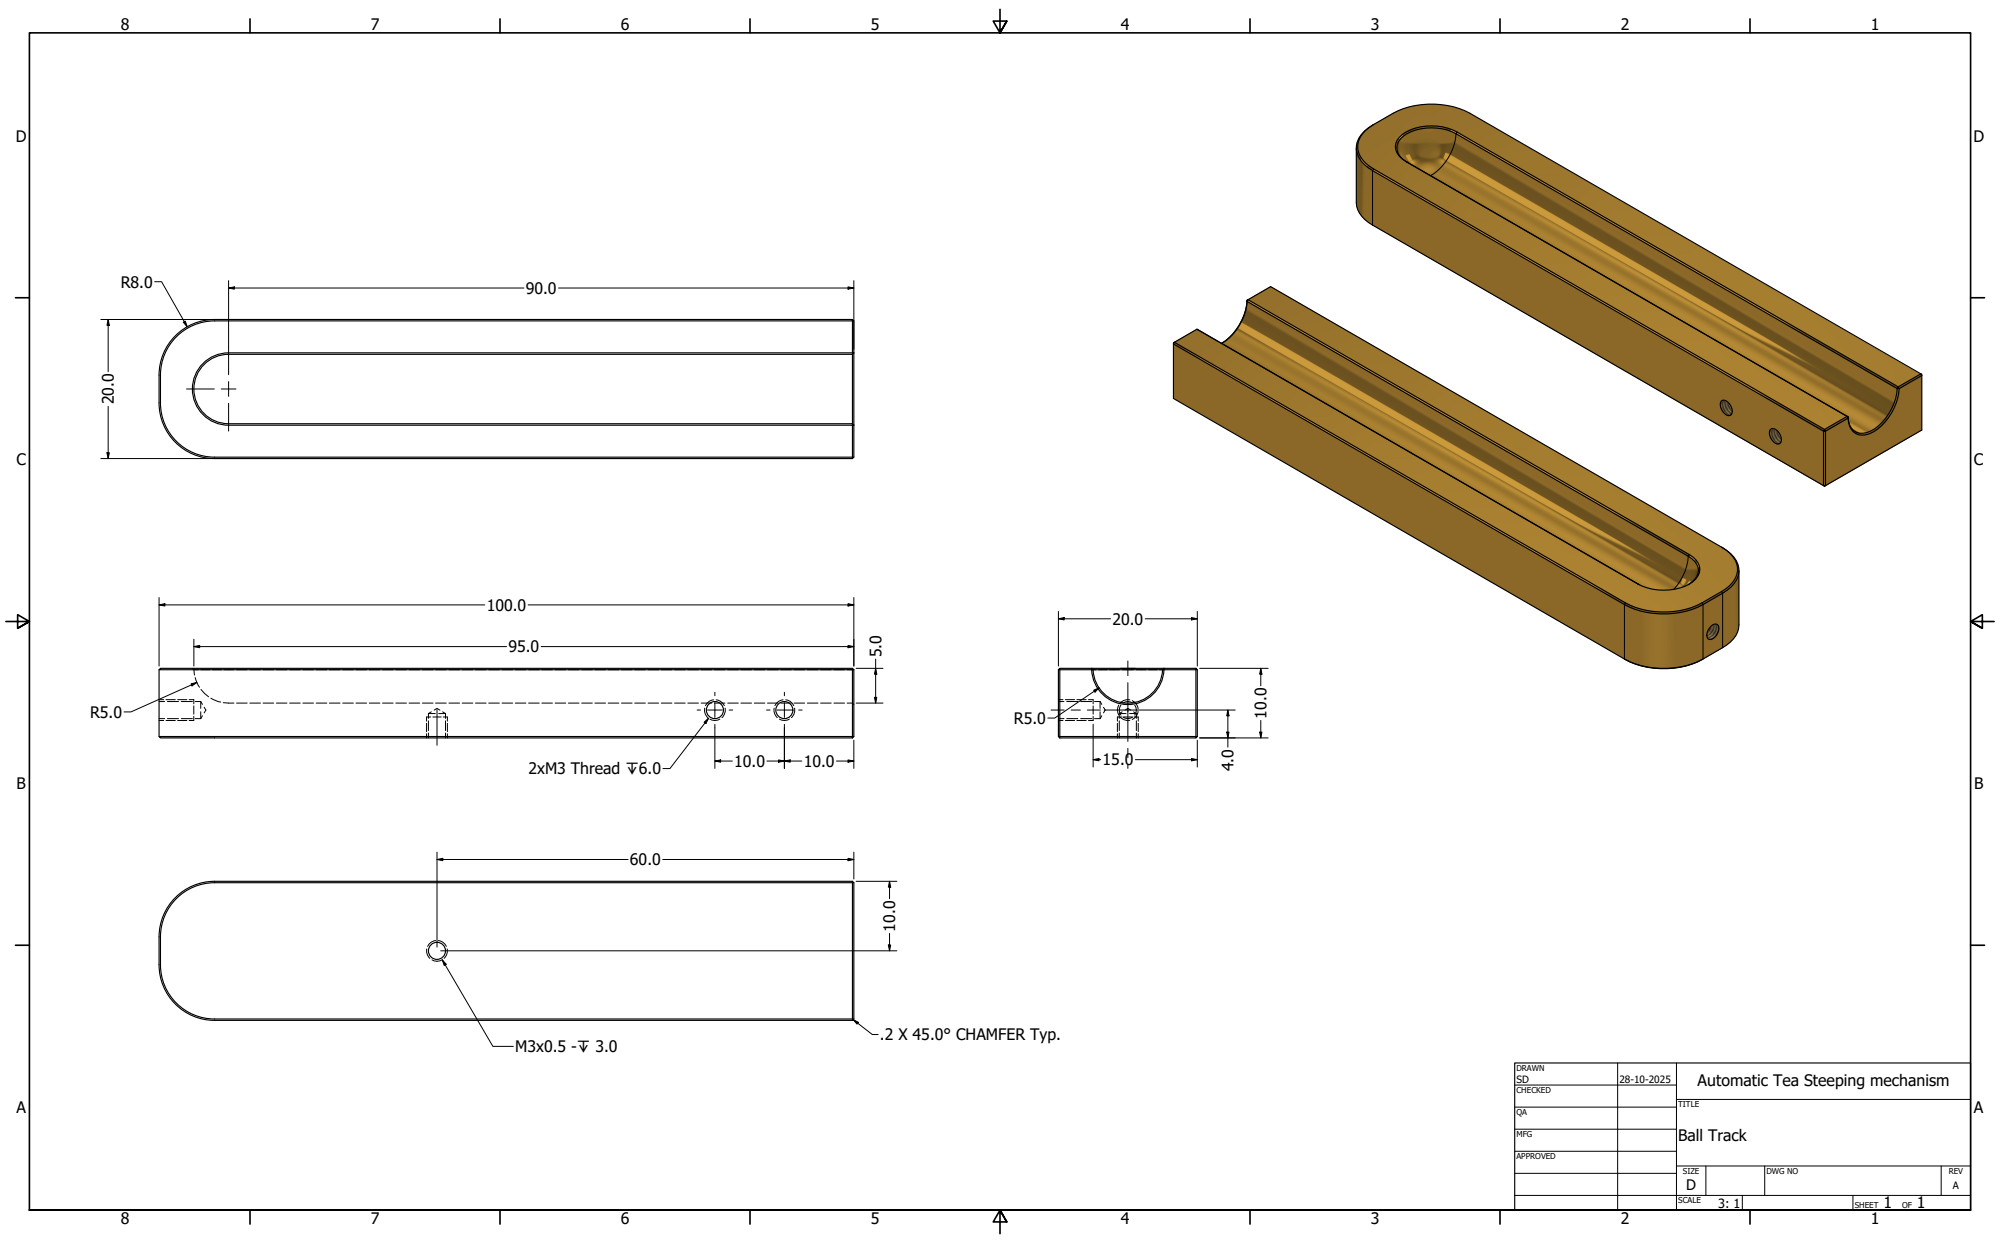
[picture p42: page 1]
Ball Track; .2 X 45.0° CHAMFER Typ.

DRAWN SD | 28-10-2025 | Automatic Tea Steeping mechanism

CHECKED

MFG

APPROVED

SIZE D | DWG NO | REV A

SCALE 3: 1 | | SHEET 1 OF 1

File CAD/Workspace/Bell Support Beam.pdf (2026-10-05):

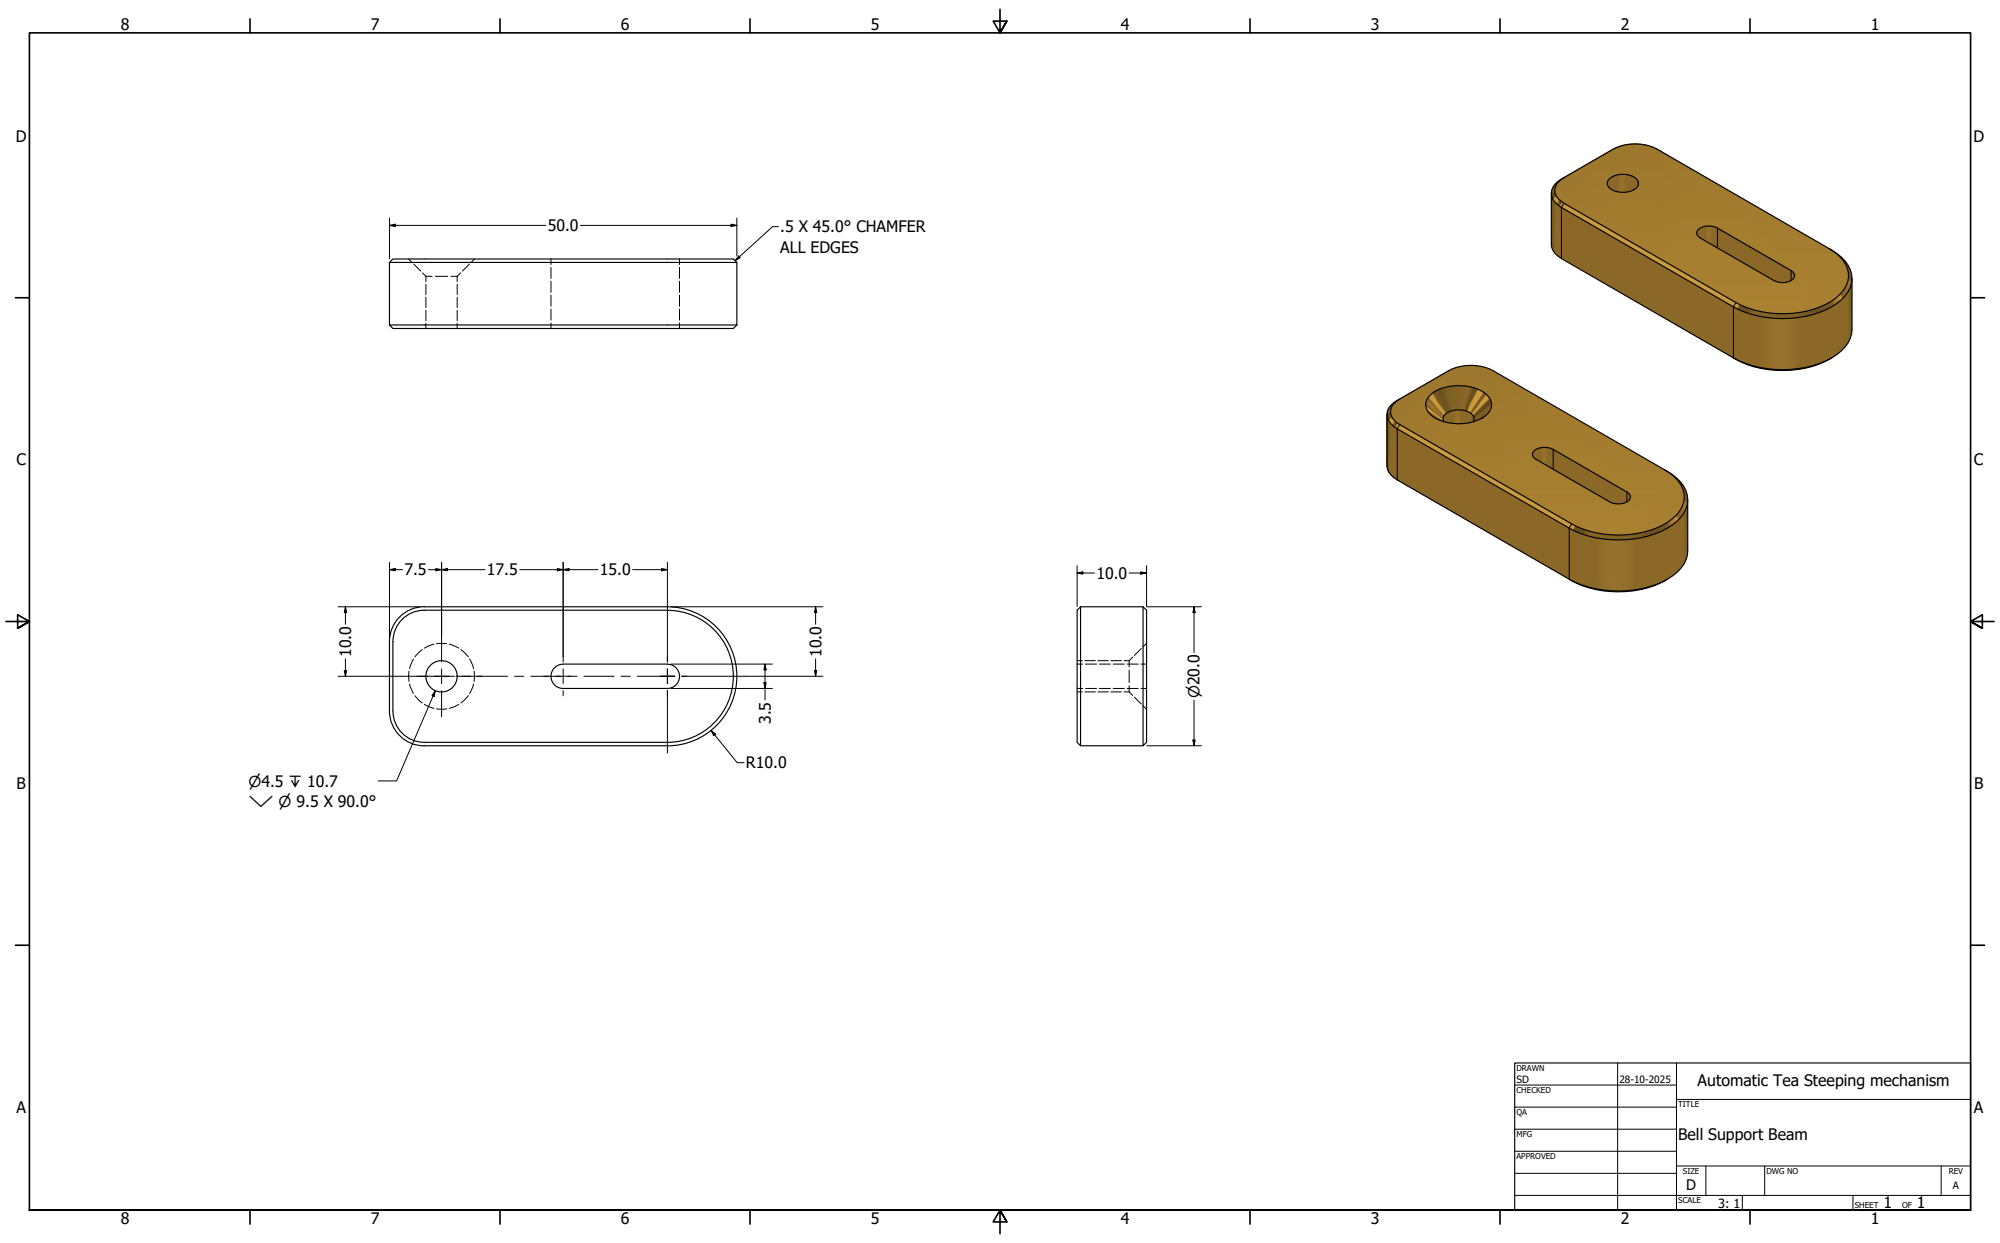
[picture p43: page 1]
.5 X 45.0° CHAMFER ALL EDGES

DRAWN SD | 28-10-2025 | Automatic Tea Steeping mechanism

CHECKED

TITLE
Bell Support Beam

MFG

APPROVED

SIZE D | DWG NO | REV A

SCALE 3: 1 | | SHEET 1 OF 1

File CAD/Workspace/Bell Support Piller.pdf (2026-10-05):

SECTION D-D SCALE 3 : 1

DRAWN SD | 28-10-2025 | Automatic Tea Steeping mechanism

CHECKED

TITLE
Bell Support Piller

MFG

APPROVED

SIZE D | DWG NO | REV A

SCALE 3 : 1 | | SHEET 1 OF 1

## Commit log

2026-10-05 Initial setup
    [19mm Circlips.stp, 3mm E Clip.stp, 3mm Rubber Washer.dwg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]
2026-10-06 update with ipt files
    [19mm Circlips.ipt, 19mm Circlips.stp, 3mm E Clip.ipt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]
2026-10-11 cleaned up BoM
2026-10-11 Replace bushing with purchased part
2026-10-12 update pulley
